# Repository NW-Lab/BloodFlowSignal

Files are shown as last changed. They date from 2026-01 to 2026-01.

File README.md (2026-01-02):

# BloodFlowSignal

複数の非侵襲的センサーを用いて、体のあちこちの心拍と血流動態を測定し、血管の状態を評価するプロジェクトです。

## プロジェクト概要

このプロジェクトは、光電式PPD（Photoplethysmography）の課題を克服し、より詳細な血管情報を取得することを目的としています。複数の異なるセンサー技術を同時に検証し、各手法の利点と欠点を比較することで、最適な血流測定システムの構築を目指します。

### 主な目標

1. **複数部位での心拍測定**: 体のあちこち（胸部、腹部、頸部、腕、脚など）で同時に心拍を測定
2. **血管硬化度の評価**: 脈波伝播速度（PWV）から血管の弾性を定量化
3. **血流動態の推定**: 複数の測定手法から血流速度と血流分布を推定
4. **光電式PPDの代替・比較**: 測定部位の制限やノイズの問題を解決

## センサー構成

本プロジェクトでは、3種類の異なるセンサー技術を実装・比較します。

### 1. マイク方式（MEMS マイクモジュール）

**製品**: [高感度ＭＥＭＳマイクモジュール SPM0404HE5H-T](https://akizukidenshi.com/catalog/g/g103200/)

**特性**:
- 周波数帯域: 100 Hz ～ 10 kHz
- 感度: -42 dBV/Pa
- 小型モジュール設計

**測定対象**:
- 心音（心臓の音）
- 呼吸音
- 体内音による圧力変化

**利点**:
- 聴診器の原理に最も近い
- 心音の周波数特性を詳細に取得可能
- 比較的安価

**欠点**:
- 周囲のノイズに敏感
- ハウジング設計（遮音性）が重要
- 増幅回路が必須

### 2. 圧力センサー方式（ピエゾ抵抗式力センサー）

**製品**: [ピエゾ抵抗式力センサー FSR402](https://akizukidenshi.com/catalog/g/g106078/)

**特性**:
- 測定範囲: 0～10 N
- 応答速度: 高速（音響測定に対応）
- 感圧抵抗型

**測定対象**:
- 体表面の脈動（機械的振動）
- 脈波伝播速度（PWV）
- 脈波形状

**利点**:
- 複数部位の同期測定が容易
- 脈波伝播速度の直接測定が可能
- 環境光の影響を受けない
- 低消費電力

**欠点**:
- ポイント測定のため複数センサーが必要
- 信号処理が必要

### 3. 光学式センサー方式（光電式PPG）

**製品**: [光学式脈波センサーモジュール](https://akizukidenshi.com/catalog/g/g116107/)

**特性**:
- 赤外線LED と フォトダイオード
- 非侵襲的な血流測定
- 従来の光電式PPD

**測定対象**:
- 血液容積の変化
- 脈拍数
- 血流の相対的な変化

**利点**:
- 従来の標準的な方法
- 実装が比較的簡単
- 脈拍数の直接測定

**欠点**:
- 測定部位が限定（指先、手首など）
- 皮膚色や厚さの影響を受けやすい
- ノイズが大きい

## システムアーキテクチャ

```
┌─────────────────────────────────────────────────────┐
│           複数部位センサー配置                        │
├─────────────────────────────────────────────────────┤
│ 胸部     │ 腹部     │ 頸部     │ 腕部     │ 脚部     │
│ (心臓)   │ (大動脈) │ (頸動脈) │ (上腕)   │ (大腿)   │
├─────────────────────────────────────────────────────┤
│ マイク   │ 圧力     │ 光学式   │ 圧力     │ 圧力     │
│ 圧力     │ センサー │ センサー │ センサー │ センサー │
│ 光学式   │          │          │          │          │
└─────────────────────────────────────────────────────┘
         ↓
┌─────────────────────────────────────────────────────┐
│         マイコン（Arduino / ESP32）                  │
│  ├─ アナログ入力処理                                │
│  ├─ デジタル入力処理（SPI）                         │
│  ├─ 信号フィルタリング                              │
│  ├─ ピーク検出                                      │
│  ├─ PWV計算                                        │
│  └─ データ出力                                      │
└─────────────────────────────────────────────────────┘
         ↓
┌─────────────────────────────────────────────────────┐
│         データ処理・可視化                            │
│  ├─ リアルタイムグラフ表示                          │
│  ├─ PWV分析                                        │
│  ├─ 血管硬化度評価                                  │
│  └─ ログ記録                                        │
└─────────────────────────────────────────────────────┘
```

## 主な測定指標

### 1. 脈波伝播速度（PWV: Pulse Wave Velocity）

複数部位での脈波到達時間差から計算：

```
PWV = 距離（m） / 時間差（s）
```

**評価基準**:
- 若い血管: PWV ≈ 15 m/s
- 硬化血管: PWV > 25 m/s

### 2. 血管コンプライアンス（DC: Distensibility Coefficient）

Bramwell-Hill方程式から計算：

```
cPWV = 1/√(ρ × DC)
```

血管の弾性を定量化。

### 3. 脈波形状解析

- 脈波の立ち上がり時間
- ピーク位置
- 脈波の幅
- 反射波の検出

### 4. 血流速度推定

複数センサーからの信号を統合して、血流速度を間接的に推定。

## ディレクトリ構成

```
BloodFlowSignal/
├── README.md                          # このファイル
├── docs/                              # ドキュメント
│   ├── sensor_specifications.md       # センサー仕様書
│   ├── measurement_protocol.md        # 測定プロトコル
│   ├── data_analysis.md               # データ分析方法
│   └── theory.md                      # 理論的背景
├── hardware/                          # ハードウェア設計
│   ├── schematics/                    # 回路図
│   ├── 3d_models/                     # 3Dプリンタ用モデル
│   └── bom.md                         # 部品表
├── firmware/                          # マイコンファームウェア
│   ├── arduino/                       # Arduino用コード
│   ├── esp32/                         # ESP32用コード
│   └── libraries/                     # 必要なライブラリ
├── software/                          # データ処理・可視化ソフト
│   ├── python/                        # Python処理スクリプト
│   ├── visualization/                 # グラフ表示
│   └── analysis/                      # 分析ツール
├── data/                              # 測定データ
│   ├── raw/                           # 生データ
│   ├── processed/                     # 処理済みデータ
│   └── results/                       # 分析結果
└── tests/                             # テストコード
    ├── unit_tests/
    ├── integration_tests/
    └── validation/
```

## クイックスタート

### 必要な部品

**センサー**:
- MEMS マイクモジュール（SPM0404HE5H-T）
- ピエゾ抵抗式力センサー（FSR402） × 5～10個
- 光学式脈波センサーモジュール

**マイコン**:
- Arduino Uno / Nano / Mega
- または ESP32

**その他**:
- ブレッドボード
- ジャンパーワイヤ
- 抵抗・コンデンサ
- 3Dプリンタ用樹脂（外装製作用）

### セットアップ手順

1. **ハードウェアの組立**
   - センサーをマイコンに接続
   - 外装（3Dプリンタ製）に組み込む

2. **ファームウェアの書き込み**
   ```bash
   cd firmware/arduino
   # Arduino IDEで対応するスケッチを開いて書き込み
   ```

3. **ソフトウェアのセットアップ**
   ```bash
   cd software/python
   pip install -r requirements.txt
   ```

4. **初期測定**
   ```bash
   python main.py
   ```

## 測定方法

### 基本的な測定プロトコル

1. **準備**
   - センサーを各部位に装着
   - 安定した姿勢で5分間休息

2. **測定**
   - 各部位で同時に脈波を記録（最低1分間）
   - 複数回測定（3～5回）

3. **分析**
   - 脈波のピーク検出
   - 部位間の時間差計算
   - PWV計算

4. **評価**
   - 血管硬化度の判定
   - 異常値の検出

## 期待される成果

### 短期的（1～3ヶ月）

- 各センサーの基本動作確認
- 信号処理アルゴリズムの開発
- 複数部位測定の実装

### 中期的（3～6ヶ月）

- PWV測定の精度検証
- 血管評価アルゴリズムの構築
- 複数センサーの統合分析

### 長期的（6～12ヶ月）

- 臨床データとの比較検証
- 機械学習による高度な分析
- 製品化への検討

## 技術的な課題と対応

### 1. ノイズ対策

**マイク方式**:
- ハウジング設計による遮音
- デジタルフィルタリング

**圧力センサー方式**:
- 低域フィルタ
- 移動平均フィルタ

**光学式方式**:
- 環境光補正
- 適応フィルタ

### 2. センサー同期

- タイムスタンプの正確な記録
- クロック同期メカニズム

### 3. 温度補正

- 各センサーの温度特性を測定
- 温度補正アルゴリズムの実装

### 4. 個人差への対応

- 体格に応じた距離補正
- 個人別のキャリブレーション

## 参考文献

- Pulse Wave Velocity: Methodology, Clinical Applications, and Interplay with Heart Rate Variability (PMC11317333)
- Transmissive-detected laser speckle contrast imaging for blood flow monitoring (Nature Light: Science & Applications)
- Pulse transit time estimation of aortic pulse wave velocity (PLoS Computational Biology)

## ライセンス

MIT License

## 貢献

このプロジェクトへの貢献を歓迎します。以下の方法で参加できます。

1. フォークしてブランチを作成
2. 変更をコミット
3. プルリクエストを送信

## 連絡先

プロジェクトに関する質問や提案は、GitHubのIssuesで報告してください。

## 更新履歴

- 2026-01-02: プロジェクト初期化、README作成

---

**注意**: このプロジェクトは研究・開発目的です。医療診断目的での使用は、適切な検証と認可を得た後に行ってください。

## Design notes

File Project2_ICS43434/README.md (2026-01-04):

# Project2: M5AtomS3とICS-43434マイクによる血流計測

## 1. はじめに

本プロジェクトは、M5Stack社のM5AtomS3とTDK InvenSense社のICS-43434 MEMSマイクを使用して、血流音を非侵襲的に計測するシステムの構築を目的とします。取得したデータはPC上のシリアルプロッターでリアルタイムに可視化し、心拍などの生体情報の簡易的なモニタリングを目指します。

## 2. 使用機材

本プロジェクトで使用する主要なハードウェアは以下の通りです。

| 機材名 | メーカー | モデル | 概要 |
| :--- | :--- | :--- | :--- |
| マイコン | M5Stack | M5AtomS3 | ESP32-S3を搭載した小型マイコンモジュール [1] |
| マイク | TDK InvenSense | ICS-43434 | I2Sデジタル出力対応のMEMSマイク [2] |

### M5AtomS3

M5AtomS3は、Wi-Fi機能を内蔵した強力なESP32-S3プロセッサ、8MBのフラッシュメモリ、0.85インチのIPSスクリーンを搭載した、非常にコンパクトで多機能な開発モジュールです。USB-Cポート経由での給電とプログラム書き込みが可能で、プロトタイピングに最適です。

### ICS-43434 MEMSマイク

ICS-43434は、高感度かつ低ノイズなデジタルMEMSマイクです。I2Sインターフェースを通じて24ビットのデジタルオーディオデータを出力するため、アナログ回路の設計が不要で、ノイズの影響を受けにくいクリーンな音声信号を取得できます。本プロジェクトでは、このマイクを用いて皮膚表面の微弱な血流音を捉えます。

## 3. ハードウェア接続

M5AtomS3とICS-43434マイクは、以下の表と配線図に従ってI2Sインターフェースで接続します。

| M5AtomS3 Pin | ICS-43434 Pin | 信号名 | 役割 |
| :--- | :--- | :--- | :--- |
| G5 | SCK | I2S Serial Clock | I2Sのビットクロック |
| G6 | WS | I2S Word Select | 左右チャンネルの選択クロック |
| G7 | SD | I2S Serial Data | マイクからのデジタル音声データ |
| 3V3 | VIN | Power | マイクへの電源供給 (3.3V) |
| GND | GND | Ground | グランド接続 |
| GND | SEL | Channel Select | チャンネル選択（GNDに接続してLeftチャンネルに設定） |

## 4. ソフトウェア

開発環境としてArduino IDEを使用し、M5AtomS3にプログラムを書き込みます。取得したデータは、USBシリアル通信を介してPCに送信され、Arduino IDEに標準で搭載されている「シリアルプロッター」機能を用いてリアルタイムで波形を可視化します。

## 5. 測定原理

手首や首などの皮膚表面に近い動脈の拍動は、微弱な音（血流音）を発生させます。ICS-43434マイクは、この音を捉えるのに十分な感度と周波数特性（50Hz〜15kHz）を持っています。取得した音声データから、心拍に同期した周期的な信号を検出することで、心拍数を推定することが可能になります。

## 6. 今後の展望

本プロジェクトで構築したシステムを基盤として、将来的には以下の様な機能拡張が考えられます。

*   **FFT（高速フーリエ変換）による周波数解析**: 血流音の周波数成分を分析し、より詳細な生体情報を抽出します。
*   **心拍数（BPM）の自動計算**: 検出した波形からピークを検出し、リアルタイムで心拍数を計算・表示します。
*   **データの保存と分析**: 計測データをファイルに保存し、長期的な健康状態のモニタリングや、機械学習を用いた異常検知などに応用します。

## 7. 参考文献

[1] M5Stack. (n.d.). *AtomS3*. M5Stack Documentation. Retrieved from https://docs.m5stack.com/en/core/AtomS3
[2] Adafruit Industries. (n.d.). *Adafruit I2S MEMS Microphone Breakout - ICS-43434*. Retrieved from https://www.adafruit.com/product/6049

## 8. 3Dプリント用ケース

血流計測の精度を向上させるため、ICS-43434マイクを皮膚に直接当てるための専用ケースを設計しました。

### ケースの特徴

*   **直接接触型**: マイクの音孔が皮膚に直接当たる構造で、振動を効率的に伝達
*   **遮音設計**: 周囲の環境音を遮断し、血流音のみを捉える
*   **持ちやすい形状**: 円筒形の持ち手で安定した測定が可能
*   **調整可能な設計**: STEP形式ファイルでFusion 360による編集が可能

### CADファイル

`CAD/`ディレクトリに以下のファイルが含まれています：

*   `microphone_case.stl` - 3Dプリント用（ケース本体）
*   `microphone_case.step` - Fusion 360編集用（ケース本体）
*   `microphone_lid.stl` - 3Dプリント用（マイク固定蓋）
*   `microphone_lid.step` - Fusion 360編集用（マイク固定蓋）

詳細な使用方法と設計仕様については、[CAD/README.md](CAD/README.md)を参照してください。

### 3Dプリント推奨設定

*   材質: PLA または ABS
*   積層ピッチ: 0.2mm
*   インフィル: 20-30%
*   プリント方向: 底面を下にして配置

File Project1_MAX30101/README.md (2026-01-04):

# Project1_MAX30101: M5AtomS3による血流計測（緑LED版）

## 概要

このプロジェクトでは、M5AtomS3マイクロコントローラーとSparkFun社のSEN-16474（MAX30101搭載）光検出器ブレークアウトボードを使用して、血流の変動を計測します。センサーから取得した**緑色光**の反射データをシリアル通信経由でPCに出力し、グラフ化することを目的とします。

緑色LEDは皮膚表面の血流変化を検出するのに最も感度が高く、心拍数測定において高いSN比（信号対雑音比）が期待できます。

## 使用機材

| 役割 | 型番 | メーカー |
|---|---|---|
| マイクロコントローラー | M5AtomS3 | M5Stack |
| センサー | SEN-16474 (MAX30101) | SparkFun |

## 接続

M5AtomS3とMAX30101センサーはI2Cインターフェースで接続します。M5AtomS3のGroveポート（HY2.0-4P）はI2C通信に対応していないため、背面のピンヘッダを使用します。

| M5AtomS3 (背面ピン) | MAX30101 (ブレークアウト) |
|---|---|
| 3.3V | 3.3V |
| GND | GND |
| G39 (SCL) | SCL |
| G38 (SDA) | SDA |

**注意:** SparkFunのブレークアウトボードはQwiicコネクタを搭載していますが、M5AtomS3のGroveポートとは互換性がありません。接続には注意してください。また、緑LEDの性能を最大限に引き出すには、センサーのVLEDピンに5Vを供給することが推奨されていますが、3.3Vでも動作します。

## セットアップ

### 1. Arduino IDEの環境設定

Arduino IDEにESP32ボードマネージャをインストールし、M5Stackのボード定義を追加する必要があります。詳細はM5Stackの公式ドキュメントを参照してください。

- [M5Stack Arduino Quick Start][1]

### 2. 必要なライブラリのインストール

Arduino IDEのライブラリマネージャから、以下の2つのライブラリをインストールしてください。

- **SparkFun MAX3010x Pulse and Proximity Sensor Library**: MAX30101センサーを制御するためのライブラリです。
- **M5Unified**: M5Stack製品群を統一的に扱うためのライブラリです。

## 使用方法

1.  このディレクトリにある`Project1_MAX30101.ino`をArduino IDEで開きます。
2.  M5AtomS3をPCに接続し、ボードとシリアルポートを正しく設定します。
3.  コードをM5AtomS3に書き込みます。
4.  Arduino IDEのシリアルプロッタ（`ツール` > `シリアルプロッタ`）を開き、ボーレートを`115200`に設定します。
5.  センサーに指を置くと、緑色光のデータがグラフとして表示されます。

## 外光ノイズ対策

MAX30101は、**Ambient Light Cancellation (ALC)** という強力な外光ノイズ除去機能を内蔵しています。この機能は、センサー内部のTrack/Hold回路によって外光の影響を自動的に測定値から差し引くことで、ダイナミックレンジを向上させます。

Arduinoコードでは、`particleSensor.setup()`関数を呼び出すことでALC機能が**自動的に有効化**されます。特別な設定は不要です。

## 注意事項

- このプロジェクトで得られるデータは、医療目的の診断や生命維持のためには使用できません。あくまで教育およびデモンストレーション目的のものです。

## 参考資料

1.  [M5Stack Docs - AtomS3][2]
2.  [SparkFun Photodetector (MAX30101) Hookup Guide][3]
3.  [MAX30101 Datasheet][4]
4.  [How to select the green LED only on the MAX30101][5]

[1]: https://docs.m5stack.com/en/arduino/atomS3
[2]: https://docs.m5stack.com/en/core/AtomS3
[3]: https://learn.sparkfun.com/tutorials/sparkfun-photodetector-max30101-hookup-guide/all
[4]: https://www.analog.com/media/en/technical-documentation/data-sheets/max30101.pdf
[5]: https://ez.analog.com/optical_sensing/w/documents/20560/how-to-select-the-green-led-only-on-the-max30101

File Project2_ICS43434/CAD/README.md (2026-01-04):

# ICS-43434マイク用血流計測ケース - 3D CADファイル

## 概要

このディレクトリには、ICS-43434 MEMSマイクを使用した血流計測用ケースの3D CADファイルが含まれています。ケースは皮膚に直接当てて使用する設計で、環境音を遮断しながら血流音を効率的に捉えることができます。

## ファイル一覧

### ケース本体

| ファイル名 | 形式 | 用途 |
| :--- | :--- | :--- |
| `microphone_case.stl` | STL | 3Dプリント用（ケース本体） |
| `microphone_case.step` | STEP | Fusion 360で編集可能（ケース本体） |

### 蓋（オプション）

| ファイル名 | 形式 | 用途 |
| :--- | :--- | :--- |
| `microphone_lid.stl` | STL | 3Dプリント用（マイク固定蓋） |
| `microphone_lid.step` | STEP | Fusion 360で編集可能（マイク固定蓋） |

## 設計仕様

### ケース本体の寸法

*   **ベース部直径**: 30mm（皮膚接触面）
*   **ベース部高さ**: 10mm
*   **持ち手部直径**: 20mm
*   **持ち手部高さ**: 40mm
*   **全体高さ**: 50mm
*   **壁厚**: 2mm

### マイク収納部

*   **基板収納スペース**: 17mm × 13.5mm × 2.5mm
*   **音孔開口部**: 直径6mm（底面中央）
*   **ケーブル切り欠き**: 幅6mm × 高さ4mm

## 使用方法

### 1. 3Dプリント

**推奨設定:**
*   材質: PLA または ABS
*   積層ピッチ: 0.2mm
*   インフィル: 20-30%
*   サポート材: 必要に応じて使用
*   プリント方向: 底面を下にして配置

**注意事項:**
*   音孔部分は貫通している必要があるため、プリント後に確認してください
*   接触面（底面）は平滑に仕上げることで、皮膚への密着性が向上します

### 2. マイクの取り付け

1. ICS-43434ブレイクアウトボードをケース上部の収納スペースに配置
2. マイクの音孔（底面ポート）がケース底面の開口部に向くように配置
3. 蓋を使用してマイクを固定（または接着剤で固定）
4. ケーブルを側面の切り欠きから引き出す

### 3. 使用時の注意

*   マイクの音孔が皮膚に直接当たるように配置してください
*   適度な圧力で皮膚に押し当てます（強く押しすぎないこと）
*   測定中はケースを動かさないように保持してください

## Fusion 360での編集

STEP形式のファイル（`microphone_case.step`）をAutodesk Fusion 360で開くことで、寸法や形状を自由に編集できます。

### 編集可能なパラメータ

*   ベース部・持ち手部の直径と高さ
*   マイク収納部のサイズ
*   音孔の直径
*   ケーブル切り欠きの位置とサイズ
*   壁厚

### 編集後の再生成

Pythonスクリプト（`generate_microphone_case.py`）を使用すれば、パラメータを変更して新しいモデルを生成できます。スクリプト内の定数を編集してから実行してください。

```bash
# 仮想環境をアクティベート
source venv/bin/activate

# スクリプトを実行
python generate_microphone_case.py
```

## 設計の背景

### 直接接触型を採用した理由

血流音は皮膚表面の微細な振動として現れます。この振動を効率的に捉えるため、マイクを皮膚に直接密着させる設計を採用しました。空気層を介さないことで、以下のメリットがあります：

*   **振動の直接伝達**: 機械的振動を効率的にマイクに伝える
*   **ノイズの低減**: 周囲の環境音（話し声、風、機械音など）の混入を防ぐ
*   **測定の安定性**: 空気層による音響特性の変動を排除

### 形状の工夫

*   **円筒形のベース**: 皮膚への均等な接触を実現
*   **持ち手部**: 安定した保持と適度な圧力の調整が可能
*   **遮音構造**: 側面からの環境音の侵入を最小限に抑制

## ライセンス

このCADファイルはオープンソースとして公開されています。自由に改変・再配布が可能です。

## 参考資料

*   [ICS-43434 データシート](https://invensense.tdk.com/wp-content/uploads/2016/02/DS-000069-ICS-43434-v1.2.pdf)
*   [Adafruit ICS-43434 製品ページ](https://www.adafruit.com/product/6049)
*   [CadQuery ドキュメント](https://cadquery.readthedocs.io/)

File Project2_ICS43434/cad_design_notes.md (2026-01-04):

# ICS-43434マイク用ケース設計メモ

## ブレイクアウトボードの寸法

Adafruit ICS-43434 ブレイクアウトボード（製品番号: 6049）の寸法：
- 基板サイズ: 約16.5mm × 12.7mm
- 厚さ: 約1.8mm
- 取り付け穴: 直径約2.5mm（4隅）
- マイク位置: 基板中央付近
- 音孔（ポート）: 基板底面（ボトムポート）

参考: https://learn.adafruit.com/adafruit-i2s-mems-microphone-breakout/downloads

## 設計コンセプト

### 目的
血流音を計測するため、マイクを皮膚に直接当てて使用するケース

### 設計方針
1. **直接接触型**: マイクの音孔が皮膚に直接当たる構造
2. **遮音性**: 周囲の環境音を遮断
3. **安定保持**: 手で持ちやすく、測定中に動かない
4. **適度な圧力**: 皮膚に軽く押し当てられる

## ケース設計仕様

### 全体構造
- 形状: 円筒形ベース + 持ち手
- 材質想定: PLA/ABS（3Dプリント）

### 寸法
- ベース部直径: 30mm（皮膚接触面）
- ベース部高さ: 10mm
- 持ち手部直径: 20mm
- 持ち手部高さ: 40mm
- 全体高さ: 約50mm

### マイク固定部
- 基板収納スペース: 17mm × 13.5mm × 2mm（余裕を持たせる）
- 音孔開口部: 直径5mm（マイク位置に合わせる）
- 固定方法: スナップフィット or ネジ固定

### 接触面
- 平面形状（皮膚に均等に当たる）
- 音孔開口部のみ貫通
- エッジは面取り（皮膚への刺激を軽減）

### ケーブル引き出し
- 側面に切り欠き（ケーブル用）
- 幅: 5mm

## 設計パラメータ（調整可能）

```python
# 基本寸法
base_diameter = 30.0  # ベース部直径 (mm)
base_height = 10.0    # ベース部高さ (mm)
handle_diameter = 20.0  # 持ち手直径 (mm)
handle_height = 40.0   # 持ち手高さ (mm)

# マイク基板
pcb_width = 17.0      # 基板幅 (mm)
pcb_length = 13.5     # 基板長さ (mm)
pcb_thickness = 2.0   # 基板厚さ (mm)

# 音孔
port_diameter = 5.0   # 音孔直径 (mm)

# 壁厚
wall_thickness = 2.0  # 壁の厚さ (mm)
```

## 製造方法
- 3Dプリント（FDM方式）
- 推奨積層ピッチ: 0.2mm
- サポート材: 必要に応じて使用

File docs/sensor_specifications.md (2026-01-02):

# センサー仕様書

## 1. MEMS マイクモジュール（SPM0404HE5H-T）

### 基本仕様

| 項目 | 仕様 |
|---|---|
| 製品名 | 高感度ＭＥＭＳマイクモジュール |
| 型番 | SPM0404HE5H-T |
| 周波数帯域 | 100 Hz ～ 10 kHz |
| 感度 | -42 dBV/Pa |
| パッケージ | BGA |
| 供給電圧 | 1.5 V ～ 3.6 V |
| 消費電流 | 約 0.5 mA |

### 特性

- **周波数特性**: 100 Hz から 10 kHz の範囲で良好な感度
- **心音周波数帯域**: 20 Hz ～ 650 Hz をカバー（100 Hz 以上）
- **呼吸音周波数帯域**: 100 Hz ～ 1000 Hz をカバー
- **小型**: 5.0 mm × 3.0 mm × 1.2 mm

### 接続方法

```
VDD -----> 電源（1.5V～3.6V）
GND -----> グラウンド
OUT -----> オーディオ出力（アナログ）
```

### 使用上の注意

1. **ハウジング設計が重要**: 周囲のノイズを遮断するため、マイクを密閉容器に収める
2. **増幅回路が必須**: マイクからの出力は非常に微弱なため、オペアンプで増幅が必要
3. **ノイズフィルタリング**: デジタルフィルタリングで環境ノイズを除去

### 測定対象

- 心音（心臓の音）
- 呼吸音
- 体内音による圧力変化

---

## 2. ピエゾ抵抗式力センサー（FSR402）

### 基本仕様

| 項目 | 仕様 |
|---|---|
| 製品名 | ピエゾ抵抗式力センサー |
| 型番 | FSR402 |
| 測定範囲 | 0～10 N |
| 感度 | 圧力依存（非線形） |
| 応答時間 | < 1 ms |
| パッケージ | 円形（直径 12.7 mm） |
| 供給電圧 | 5 V |

### 特性

- **応答速度**: 0.8 ms（脈波測定に十分）
- **周波数帯域**: 約 1.25 kHz（心音・呼吸音をカバー）
- **非線形特性**: 圧力が増加するほど抵抗値が低下
- **温度特性**: 温度による変化あり（補正が必要）

### 接続方法

```
FSR402を分圧回路で使用：

        5V
        |
        R（10kΩ）
        |
    +---+----> ADC入力
    |
   FSR402
    |
   GND
```

### 使用上の注意

1. **分圧回路が必須**: FSR402は可変抵抗のため、分圧回路で電圧に変換
2. **温度補正**: 温度による特性変化を補正
3. **キャリブレーション**: 個別のキャリブレーションが必要
4. **複数個使用**: 複数部位測定には複数個のセンサーが必要

### 測定対象

- 体表面の脈動（機械的振動）
- 脈波伝播速度（PWV）
- 脈波形状

---

## 3. 光学式脈波センサーモジュール

### 基本仕様

| 項目 | 仕様 |
|---|---|
| 製品名 | 光学式脈波センサーモジュール |
| 型番 | （確認中） |
| 光源 | 赤外線LED（660 nm または 940 nm） |
| 検出器 | フォトダイオード |
| 周波数帯域 | DC ～ 数 kHz |
| 供給電圧 | 3.3 V ～ 5 V |
| 消費電流 | 約 10～20 mA |

### 特性

- **非侵襲的**: 皮膚表面の血流を光学的に測定
- **脈拍検出**: 血液容積の変化から脈拍を検出
- **相対測定**: 絶対的な血流量ではなく、相対的な変化を測定

### 接続方法

```
LED+ -----> 電源（制限抵抗経由）
LED- -----> GND
PD+ -----> アナログ入力（増幅回路経由）
PD- -----> GND
```

### 使用上の注意

1. **測定部位の限定**: 指先、手首など、光が透過する部位のみ
2. **皮膚色の影響**: メラニン色素が多い場合、信号が弱くなる
3. **環境光の影響**: 外部光源の変動が測定値に影響
4. **密着性が重要**: センサーと皮膚の密着度が測定精度に影響

### 測定対象

- 血液容積の変化
- 脈拍数
- 血流の相対的な変化

---

## センサー比較表

| 特性 | マイク | 圧力センサー | 光学式 |
|---|---|---|---|
| **周波数帯域** | 100 Hz ～ 10 kHz | DC ～ 1.25 kHz | DC ～ 数 kHz |
| **応答速度** | 高速 | 高速（< 1 ms） | 中速 |
| **測定部位** | 任意 | 任意 | 限定（指先など） |
| **ノイズ耐性** | 低 | 高 | 中 |
| **環境光影響** | なし | なし | あり |
| **複数部位対応** | 容易 | 容易 | 困難 |
| **コスト** | 低 | 低 | 低 |
| **実装難易度** | 中 | 低 | 低 |

---

## 信号処理フロー

### マイク方式

```
マイク出力
  ↓
増幅回路
  ↓
ADC変換
  ↓
デジタルフィルタリング（ハイパスフィルタ）
  ↓
周波数解析（FFT）
  ↓
心音検出・分析
```

### 圧力センサー方式

```
FSR402出力
  ↓
分圧回路
  ↓
ADC変換
  ↓
デジタルフィルタリング（ローパス＋ハイパス）
  ↓
ピーク検出
  ↓
時間差計算
  ↓
PWV計算
```

### 光学式方式

```
フォトダイオード出力
  ↓
増幅回路
  ↓
ADC変換
  ↓
デジタルフィルタリング
  ↓
ピーク検出
  ↓
脈拍数計算
```

---

## キャリブレーション方法

### マイク方式

1. 既知の周波数信号を入力
2. 出力の周波数特性を測定
3. 補正係数を計算

### 圧力センサー方式

1. 既知の圧力を加える
2. 出力電圧を測定
3. 圧力-電圧特性曲線を作成
4. 非線形補正を実装

### 光学式方式

1. 既知の脈拍数で測定
2. 検出された脈拍数と比較
3. 補正係数を計算

---

## トラブルシューティング

### マイク方式

| 問題 | 原因 | 対策 |
|---|---|---|
| 出力が小さい | 増幅不足 | 増幅回路のゲインを上げる |
| ノイズが多い | 外部ノイズ | ハウジング改善、フィルタ強化 |
| 周波数特性が悪い | フィルタ設定 | フィルタ係数を調整 |

### 圧力センサー方式

| 問題 | 原因 | 対策 |
|---|---|---|
| 出力が不安定 | 接触不良 | センサー接触面を確認 |
| 温度ドリフト | 温度変化 | 温度補正を実装 |
| 非線形性 | センサー特性 | 非線形補正を実装 |

### 光学式方式

| 問題 | 原因 | 対策 |
|---|---|---|
| 信号が弱い | 皮膚色 | LED電流を増加 |
| ノイズが多い | 環境光 | 環境光補正を実装 |
| 脈拍検出失敗 | 密着不良 | センサー装着を改善 |

---

## 参考資料

- SPM0404HE5H-T データシート
- FSR402 データシート
- 光学式脈波センサー仕様書

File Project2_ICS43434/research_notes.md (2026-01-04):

# ICS-43434マイクとM5AtomS3の調査結果

## ICS-43434 MEMS マイクロフォン仕様

### 基本情報
- 製品: Adafruit I2S MEMS Microphone Breakout - ICS-43434
- 製品URL: https://www.adafruit.com/product/6049
- チップ: TDK ICS43434
- インターフェース: I2S (デジタル出力)

### 技術仕様
- 感度: −26 dB FS ±1dB
- SNR (High Performance Mode): 65 dBA
- SNR (Low Power Mode): 64 dBA
- 消費電流 (High Performance Mode): 490 µA
- 消費電流 (Low Power Mode): 230 µA
- Acoustic Overload Point (AOP): 120 dB SPL
- サンプルレート (High Performance Mode): 23 ~ 51.6 kHz
- サンプルレート (Low Power Mode): 6.25 ~ 18.75 kHz
- 周波数範囲: 50Hz - 15KHz (一般的なオーディオ記録に適している)
- ローパスフィルター: 24KHz以上をカット
- データ出力: 24ビット

### ピン配置
- Clock (SCK/BCK): I2Sクロック信号
- Data (SD): I2Sデータ出力
- Word Select (WS/LRCLK): 左右チャンネル選択
- Select (SEL): チャンネル選択 (GND=Left, VDD=Right)
- VIN: 電源入力 (1.6V - 3.6V)
- GND: グランド

### 重要な特徴
- モノラルマイク（ステレオには2個必要）
- ボトムポート（底面に音孔）
- 5Vロジックには非対応（3.3V専用）
- ESP32、RP2040、SAMD21/51などのI2S対応マイコンに最適

## M5AtomS3 仕様

### 基本情報
- 製品URL: https://docs.m5stack.com/en/core/AtomS3
- SoC: ESP32-S3FN8
- Flash: 8MB
- サイズ: 24.0 x 24.0 x 12.9mm

### 電源仕様
- 入力電源: 5V (USB Type-C)
- 出力電圧: 3.3V
- DC-DC: SY8089

### 利用可能なGPIOピン
- G5, G6, G7, G8, G38, G39 (底面に配置)

### I2C使用状況
- MPU6886 (IMU): I2C Address 0x68
  - SDA: GPIO38
  - SCL: GPIO39

### 内蔵ペリフェラル
- 0.85インチ LCD (SPI接続)
  - MOSI: G21
  - SCK: G17
  - CS: G15
  - RS: G33
  - RST: G34
  - LCD_BL: G16

### HY2.0-4Pポート
- GND: Black
- 5V: Red
- G2: Yellow
- G1: White

### I2S接続の推奨ピン
ESP32-S3はI2S0とI2S1の2つのI2Sペリフェラルを持つ。
利用可能なGPIOピン（G5, G6, G7, G8）をI2S接続に使用可能。

推奨配線:
- I2S SCK (Clock): GPIO5
- I2S WS (Word Select): GPIO6
- I2S SD (Data): GPIO7
- SEL: GND (Left channel) または 3.3V (Right channel)
- VIN: 3.3V
- GND: GND

## 血流計測への応用

### 測定原理
マイクロフォンを使用して血流音（血管の拍動音）を検出する。
- 皮膚表面に近い血管（手首、首など）の拍動音を検出
- 低周波成分（1-10Hz程度）に心拍情報が含まれる
- ICS-43434の周波数範囲は50Hz-15KHzなので、低周波の心拍音検出に適している

### データ処理
1. I2Sインターフェースで24ビットデジタルデータを取得
2. サンプリングレート: 16kHz または 44.1kHz
3. データをシリアル経由でPCに送信
4. Arduino IDEのシリアルプロッターでリアルタイム表示

## 参考資料
- ICS-43434 Datasheet: https://invensense.tdk.com/wp-content/uploads/2016/02/DS-000069-ICS-43434-v1.2.pdf
- Adafruit製品ガイド: https://learn.adafruit.com/adafruit-i2s-mems-microphone-breakout
- M5AtomS3 Arduino Library: https://github.com/m5stack/M5Unified
- ESP32-S3 I2S Documentation: https://docs.espressif.com/projects/esp-idf/en/stable/esp32s3/api-reference/peripherals/i2s.html

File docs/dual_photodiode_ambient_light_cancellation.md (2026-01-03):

# 2個フォトダイオード方式の外光除去技術

## 概要

光学式PPGセンサーにおいて、受光部（フォトダイオード）が2個ある場合の外光除去技術について解説します。この技術は、**LED ON-OFF方式と同じ基本原理**（時間的な差分を取る）を使用しますが、**アナログ領域で電荷再分配により実現**する点が大きく異なります。

---

## 基本原理: 交互サンプリングと電荷再分配

### 動作の概要

2個フォトダイオード方式（正確には**2個電荷リザーバ方式**）では、以下の3つのフェーズで外光除去を行います。

1. **Phase 1**: LED ON時に信号をサンプリングし、電荷リザーバCrに保存
2. **Phase 2**: LED OFF時に信号をサンプリングし、電荷リザーバCaに保存
3. **Phase 3**: 2つの電荷リザーバを**逆極性で接続**し、電荷再分配により差分を取る

この方式により、外光成分が物理的に打ち消され、純粋なPPG信号のみが抽出されます。

---

## 詳細な動作原理

### Phase 1: LED ON時のサンプリング

**スイッチ状態**:
- Switch S1: 接続
- Switch S2, S3: 切断

**測定内容**: LED光（PPG信号）+ 外光

**保存先**: 電荷リザーバ Cr

**保存される電荷**:
```
Qr = Cr × V_ph1
```

ここで、`V_ph1 = V_LED + V_AL`
- `V_LED`: LED光による信号（PPG信号）
- `V_AL`: 外光による信号（ノイズ）

### Phase 2: LED OFF時のサンプリング

**スイッチ状態**:
- Switch S1: 切断
- Switch S2: 接続
- Switch S3: 切断

**測定内容**: 外光のみ

**保存先**: 電荷リザーバ Ca

**保存される電荷**:
```
Qa = Ca × V_ph2
```

ここで、`V_ph2 = V_AL`（LED OFFのため、外光のみ）

### Phase 3: 電荷再分配

**スイッチ状態**:
- Switch S1, S2: 切断
- Switch S3: 接続

**動作**: CrとCaを**逆極性で接続**

**極性制御**:
- `Polarity = High`: Crのプラスノードを Caのマイナスノードに接続
- `Polarity = Low`: Crのプラスノードを Caのプラスノードに接続

**出力電圧**（Cr = Caの場合）:
```
V_out = (V_ph1 - V_ph2) / 2
      = (V_LED + V_AL - V_AL) / 2
      = V_LED / 2
```

**結果**: 外光成分（V_AL）が完全に除去され、LED光による信号（PPG信号）のみが残ります。

---

## LED ON-OFF方式との比較

| 項目 | LED ON-OFF方式（デジタル差分） | 2個電荷リザーバ方式（アナログ差分） |
|---|---|---|
| **基本原理** | LED ON時とOFF時の差分を取る | 同じ（時間的な差分） |
| **差分計算の場所** | デジタル演算（マイコン内） | アナログ回路（電荷再分配） |
| **外光除去のタイミング** | ADC変換後、デジタル演算で除去 | ADC変換前、アナログ段階で除去 |
| **消費電力** | 中程度（ADC + デジタル演算） | 低い（アナログ回路のみ） |
| **ダイナミックレンジ** | 外光成分がADCレンジを占有 | 外光除去後にADC変換（有効活用） |
| **精度** | ADC分解能に依存 | 電荷再分配の精度に依存 |
| **回路複雑度** | 低い（シンプル） | 中程度（スイッチ制御が必要） |
| **リアルタイム性** | デジタル演算の遅延あり | 瞬時に完了（遅延ほぼなし） |
| **実装** | マイコン + ADC | 電荷リザーバ + スイッチ + 制御回路 |

---

## 利点と欠点

### 利点

**1. 低消費電力**

アナログ領域で外光除去が完了するため、デジタル演算が不要です。これにより、消費電力を大幅に削減できます。

**実測値**: 26.4 μW（Kim et al., 2015）

**2. 高ダイナミックレンジ**

外光成分を除去してからADC変換するため、ADCのダイナミックレンジをPPG信号に集中できます。これにより、微弱なPPG信号を高精度に測定可能です。

**3. リアルタイム処理**

電荷再分配は瞬時に完了するため、リアルタイムで外光除去が可能です。遅延がほとんどありません。

**4. 高精度**

電荷再分配により、外光成分を物理的に打ち消すため、デジタル演算による丸め誤差がありません。

### 欠点

**1. 回路複雑度の増加**

2つの電荷リザーバ（コンデンサ）とスイッチ制御回路が必要です。タイミング制御が重要になります。

**2. 電荷リザーバのマッチング**

CrとCaのキャパシタンスが正確に一致している必要があります。マッチング誤差があると、外光除去が不完全になります。

**3. スイッチのリーク電流**

スイッチのリーク電流により、保存された電荷が減衰する可能性があります。高品質なスイッチ（低リーク電流 <1 pA）が必要です。

**4. 集積回路（IC）化が必要**

この技術は、通常、専用の集積回路（ASIC）として実装されます。ディスクリート部品での実装は困難です。

---

## 実装上の注意点

### 1. タイミング制御

Phase 1、Phase 2、Phase 3のタイミングを正確に制御する必要があります。

**推奨タイミング**:
- **Phase 1（LED ON）**: 4 ms
- **Phase 2（LED OFF）**: 4 ms
- **Phase 3（電荷再分配）**: 数μs～数十μs

**タイミング図**:
```
LED:     ████████________████████________
         |  ON  |  OFF  |  ON  |  OFF  |
         
Phase:   |  1   |   2   |  1   |   2   |
         
Switch:  S1 ON  S2 ON   S1 ON  S2 ON
         S3 OFF S3 OFF  S3 OFF S3 OFF
         
Charge:  Cr保存 Ca保存  Cr保存 Ca保存
         
Output:         S3 ON          S3 ON
                再分配          再分配
```

### 2. 電荷リザーバのサイズ

電荷リザーバ（Cr, Ca）のキャパシタンスは、以下の要素を考慮して決定します。

**大きいキャパシタンス（例: 10 pF以上）**:
- **利点**: ノイズ耐性が高い、リーク電流の影響が小さい
- **欠点**: チップ面積が大きい、電荷再分配に時間がかかる

**小さいキャパシタンス（例: 1 pF以下）**:
- **利点**: チップ面積が小さい、高速動作
- **欠点**: ノイズ耐性が低い、リーク電流の影響が大きい

**推奨値**: 3～10 pF（ノイズ耐性と速度のバランス）

### 3. スイッチの選択

スイッチには、低リーク電流、低オン抵抗、高速スイッチングが求められます。

**推奨スイッチ**:
- **CMOS伝送ゲート（Transmission Gate）**: NMOSとPMOSを並列接続
- **低リーク電流**: <1 pA
- **低オン抵抗**: <100 Ω
- **スイッチング時間**: <1 μs

### 4. マッチング精度

CrとCaのキャパシタンスは、高精度でマッチングする必要があります。

**推奨マッチング精度**: ±0.1%以内

**実装方法**:
- 同じレイアウト、同じサイズのキャパシタを使用
- 温度変動の影響を最小化するため、温度係数の小さいキャパシタを選択

---

## 本プロジェクトでの適用可能性

### 使用予定の光学式センサー

**製品**: [秋月電子 光学式脈波センサー](https://akizukidenshi.com/catalog/g/g116107/)

このセンサーは、既製品のモジュールであり、内部回路の詳細は不明です。おそらく、以下のいずれかの方式を使用していると推定されます。

1. **LED ON-OFF方式（デジタル差分）**: 最も一般的
2. **2個電荷リザーバ方式（アナログ差分）**: 高性能モジュールの場合

### 実装方法

**ケース1: モジュールがLED ON-OFF方式を使用している場合**

マイコン（Seeeduino XIAO）で以下の処理を実装します。

1. LED ON時にADCサンプリング → `V_on`
2. LED OFF時にADCサンプリング → `V_off`
3. デジタル演算で差分を計算 → `V_ppg = V_on - V_off`

**ケース2: モジュールが2個電荷リザーバ方式を使用している場合**

モジュール内部で外光除去が完了しているため、マイコンでは単純にADCサンプリングするだけで済みます。

**推奨**: まずは、モジュールのデータシートを確認し、内部回路の詳細を把握することが重要です。データシートが入手できない場合は、実験的にLED ON-OFF方式を実装し、外光除去の効果を確認してください。

---

## 参考文献

1. Jongpal Kim, Jihoon Kim, Hyoungho Ko, "Low-Power Photoplethysmogram Acquisition Integrated Circuit with Robust Light Interference Compensation," Sensors, 2015.
   - DOI: 10.3390/s16010046
   - PMCID: PMC4732079

2. 島崎拓則ら, "光電脈波計の原理を利用した適応フィルタによる運動中の心拍数センシング," 生体医工学, 2016.

3. Analog Devices, "ADPD144RI Data Sheet," 2019.

4. Maxim Integrated (Analog Devices), "MAX86177 Data Sheet," 2022.

---

## まとめ

2個フォトダイオード方式（正確には2個電荷リザーバ方式）の外光除去技術は、**LED ON-OFF方式と同じ基本原理**（時間的な差分を取る）を使用しますが、**アナログ領域で電荷再分配により実現**する点が大きく異なります。

この方式は、**低消費電力**、**高ダイナミックレンジ**、**リアルタイム処理**という利点があり、ウェアラブルデバイスに最適です。ただし、回路複雑度が増加し、電荷リザーバのマッチングとスイッチのリーク電流に注意が必要です。

本プロジェクトでは、使用予定の光学式センサーモジュールの内部回路を確認し、適切な実装方法を選択することが重要です。

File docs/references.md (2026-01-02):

# 参考文献・技術資料

本プロジェクトで参考にした論文、技術資料、データシートをまとめています。

---

## 目次

1. [脈波伝播速度（PWV）と血管評価](#脈波伝播速度pwvと血管評価)
2. [脈波到達時間（PAT）と血圧推定](#脈波到達時間patと血圧推定)
3. [光学式血流測定](#光学式血流測定)
4. [センサー技術](#センサー技術)
5. [データシート](#データシート)
6. [その他の技術資料](#その他の技術資料)

---

## 脈波伝播速度（PWV）と血管評価

### 主要論文

#### 1. Pulse transit time estimation of aortic pulse wave velocity and blood pressure using machine learning and simulated training data

**著者**: Janne M J Huttunen, Leo Kärkkäinen, Harri Lindholm  
**掲載誌**: PLoS Computational Biology, 2019  
**URL**: https://pmc.ncbi.nlm.nih.gov/articles/PMC6711549/  
**DOI**: 10.1371/journal.pcbi.1007259

**概要**:
- 心血管モデリングを用いた仮想被験者データベースの生成
- 機械学習（ガウス過程回帰）による大動脈PWV、血圧、一回拍出量の推定
- 光電式PPG信号から導出された脈波通過時間を使用
- 大動脈PWVの推定精度: r > 0.9（左頸動脈測定時）

**本プロジェクトへの示唆**:
- 複数部位での脈波測定から機械学習でPWVを高精度推定可能
- 足から足への脈波通過時間とピーク位置の組み合わせが有効

---

#### 2. Pulse transit time estimation of aortic pulse wave velocity

**著者**: 複数著者  
**掲載誌**: PMC6711549  
**URL**: https://pmc.ncbi.nlm.nih.gov/articles/PMC6711549/

**概要**:
- PWVの計算式: PWV = 距離（m） / 伝播時間（s）
- 2つの異なる動脈部位での脈波到達時間測定が基本
- 血管硬化度の評価に有効

**本プロジェクトへの示唆**:
- 複数部位測定の理論的基礎
- PWV計算の標準的な方法

---

#### 3. Assessment of Arterial Distensibility by Automatic Pulse Wave Velocity Measurement

**著者**: 複数著者  
**掲載誌**: Hypertension  
**URL**: https://www.ahajournals.org/doi/10.1161/01.HYP.26.3.485

**概要**:
- PWVは血管壁の伸展性と逆相関
- 自動PWV測定による動脈コンプライアンス評価
- Bramwell-Hill方程式: cPWV = 1/√(ρ × DC)

**本プロジェクトへの示唆**:
- PWVから血管コンプライアンス（弾性）を定量化可能
- 血管硬化度の客観的評価指標

---

#### 4. 新しい動脈硬化指標としての血圧脈波検査

**著者**: 松井芳夫  
**掲載誌**: 日本医療機器学会誌, 2010  
**URL**: https://www.jstage.jst.go.jp/article/jjmi/80/4/80_4_343/_pdf/-char/en

**概要**:
- 若年者のPWV: 約15 m/s
- 高齢者のPWV: 25 m/s以上（血管硬化）
- 2点間の距離と時間差からPWVを算出

**本プロジェクトへの示唆**:
- PWVの年齢別基準値
- 血管硬化度の判定基準

---

#### 5. 高血圧動脈弾性功能無創性評価（中国語）

**著者**: 複数著者  
**URL**: http://zhgxyzz.xml-journal.net/cn/article/pdf/preview/10.16439/j.cnki.1673-7245.2002.06.001.pdf

**概要**:
- 非侵襲的な動脈弾性機能評価
- 脈波伝播時間と血管内血流速度の関係
- 動脈可拡張性の定量的指標

**本プロジェクトへの示唆**:
- 非侵襲的測定の実用性
- 血管弾性の多角的評価

---

## 脈波到達時間（PAT）と血圧推定

### 主要論文

#### 6. Pulse Arrival Time as a Surrogate of Blood Pressure

**著者**: 複数著者  
**掲載誌**: Nature Scientific Reports, 2021  
**URL**: https://www.nature.com/articles/s41598-021-01358-4

**概要**:
- PATは血圧の代替指標として有用
- 圧力波の速度は多くのパラメータに依存
- 層流血流モデルでの良好な性能

**本プロジェクトへの示唆**:
- PATから血圧を推定可能
- 複数部位測定での血圧分布推定

---

#### 7. Pulse Arrival Velocity for Tracking Exercise-Induced Blood Pressure Changes

**著者**: LE Ryan et al.  
**掲載誌**: ScienceDirect, 2025  
**URL**: https://www.sciencedirect.com/science/article/pii/S1443950625016555

**概要**:
- 新しい指標PAV（Pulse Arrival Velocity）の提案
- PAV = L/PAT（距離/脈波到達時間）
- 運動誘発性血圧変化の追跡に有効

**本プロジェクトへの示唆**:
- PAVという新しい指標の可能性
- 動的な血圧変化の追跡

---

#### 8. Measuring Multi-Site Pulse Transit Time with an AI-Enabled System

**著者**: 複数著者  
**掲載誌**: arXiv, 2025  
**URL**: https://arxiv.org/html/2510.18141v1

**概要**:
- AI対応システムによる複数部位PTT測定
- 非接触測定の可能性
- 心血管疾患の事前スクリーニングへの応用

**本プロジェクトへの示唆**:
- 複数部位測定の重要性
- AI/機械学習の活用可能性

---

#### 9. Evaluation of the Linear Relationship Between Pulse Arrival Time and Blood Pressure

**著者**: B Escobar-Restrepo et al.  
**掲載誌**: Frontiers in Physiology, 2018  
**URL**: https://www.frontiersin.org/journals/physiology/articles/10.3389/fphys.2018.01848/full

**概要**:
- PATと血圧の線形関係の評価
- ECGから侵襲的血圧測定までのPAT測定
- 線形関係の程度を実証

**本プロジェクトへの示唆**:
- PATと血圧の関係性の理解
- 測定精度の向上

---

## 光学式血流測定

### 主要論文

#### 10. Transmissive-Detected Laser Speckle Contrast Imaging for Blood Flow Monitoring

**著者**: 複数著者  
**掲載誌**: Nature Light: Science & Applications, 2021  
**URL**: https://www.nature.com/articles/s41377-021-00682-8  
**DOI**: 10.1038/s41377-021-00682-8

**概要**:
- レーザースペックルコントラスト画像法（LSCI）
- 透過検出型LSCIによる血流モニタリング
- 時間分解能: ミリ秒オーダー
- 空間分解能: マイクロメートルオーダー

**本プロジェクトへの示唆**:
- 光学式血流測定の高度な手法
- 血流速度の直接測定の可能性
- 将来的な拡張オプション

---

#### 11. Photoplethysmography (PPG) Signal Processing and Analysis

**著者**: 複数著者  
**概要**:
- 光電式PPGの基本原理
- 信号処理とノイズ除去
- 脈拍検出アルゴリズム

**本プロジェクトへの示唆**:
- 光学式センサーの信号処理方法
- PPGの限界と課題の理解

---

## センサー技術

### 技術資料

#### 12. MEMS Microphone Technology Overview

**概要**:
- MEMSマイクの動作原理
- 周波数特性と感度
- ノイズ特性

**本プロジェクトへの示唆**:
- マイク方式の技術的基礎
- 心音測定への応用

---

#### 13. Force Sensitive Resistor (FSR) Technology

**概要**:
- ピエゾ抵抗式力センサーの原理
- 非線形特性と補正方法
- 応答速度と精度

**本プロジェクトへの示唆**:
- 圧力センサー方式の技術的基礎
- キャリブレーション方法

---

#### 14. Optical Heart Rate Sensor Design

**概要**:
- 光学式心拍センサーの設計
- LED波長の選択
- フォトダイオードの配置

**本プロジェクトへの示唆**:
- 光学式センサーの実装方法
- 測定精度の向上

---

## データシート

### センサー関連

#### 15. SPM0404HE5H-T MEMS Microphone Datasheet

**製造元**: Knowles  
**URL**: （秋月電子通商で入手可能）

**主要仕様**:
- 周波数帯域: 100 Hz ～ 10 kHz
- 感度: -42 dBV/Pa
- 供給電圧: 1.5 V ～ 3.6 V

---

#### 16. FSR402 Force Sensitive Resistor Datasheet

**製造元**: Interlink Electronics  
**URL**: （秋月電子通商で入手可能）

**主要仕様**:
- 測定範囲: 0～10 N
- 応答時間: < 1 ms
- 非線形特性あり

---

#### 17. Optical Pulse Sensor Module Datasheet

**URL**: https://akizukidenshi.com/catalog/g/g116107/

**主要仕様**:
- 赤外線LED（660 nm または 940 nm）
- フォトダイオード検出器
- 供給電圧: 3.3 V ～ 5 V

---

### マイコン関連

#### 18. ATSAMD21G18 Microcontroller Datasheet

**製造元**: Microchip  
**URL**: https://www.microchip.com/

**主要仕様**:
- ARM Cortex-M0+ 48 MHz
- ROM: 256 kB
- RAM: 32 kB
- GPIO: 11ピン

---

#### 19. Seeeduino XIAO Documentation

**製造元**: Seeed Studio  
**URL**: https://wiki.seeedstudio.com/Seeeduino-XIAO/

**概要**:
- ピン配置図
- Arduino IDE設定方法
- サンプルコード

---

## その他の技術資料

### 信号処理

#### 20. Digital Signal Processing for Biomedical Applications

**概要**:
- 生体信号のデジタルフィルタリング
- ノイズ除去技術
- ピーク検出アルゴリズム

**本プロジェクトへの示唆**:
- 脈波信号の前処理方法
- リアルタイム処理の実装

---

### 機械学習

#### 21. Machine Learning for Cardiovascular Signal Analysis

**概要**:
- 心血管信号の機械学習分析
- 特徴抽出
- 分類・回帰モデル

**本プロジェクトへの示唆**:
- PWV推定の高度化
- 異常検出アルゴリズム

---

### 医療機器設計

#### 22. Medical Device Design Guidelines

**概要**:
- 医療機器の安全基準
- 生体適合性
- 電磁両立性（EMC）

**本プロジェクトへの示唆**:
- 安全性の確保
- 将来的な製品化への準備

---

## 関連ウェブサイト

### 学術データベース

- **PubMed Central**: https://www.ncbi.nlm.nih.gov/pmc/
- **IEEE Xplore**: https://ieeexplore.ieee.org/
- **Nature**: https://www.nature.com/
- **Frontiers**: https://www.frontiersin.org/

### 技術コミュニティ

- **Arduino Forum**: https://forum.arduino.cc/
- **Seeed Studio Wiki**: https://wiki.seeedstudio.com/
- **GitHub**: https://github.com/

### 部品調達

- **秋月電子通商**: https://akizukidenshi.com/
- **Digi-Key**: https://www.digikey.jp/
- **Mouser**: https://www.mouser.jp/

---

## 引用形式

本プロジェクトの論文や資料を引用する際は、以下の形式を使用してください。

### APA形式

```
Huttunen, J. M. J., Kärkkäinen, L., & Lindholm, H. (2019). Pulse transit time estimation of aortic pulse wave velocity and blood pressure using machine learning and simulated training data. PLoS Computational Biology, 15(8), e1007259. https://doi.org/10.1371/journal.pcbi.1007259
```

### IEEE形式

```
J. M. J. Huttunen, L. Kärkkäinen, and H. Lindholm, "Pulse transit time estimation of aortic pulse wave velocity and blood pressure using machine learning and simulated training data," PLoS Comput. Biol., vol. 15, no. 8, p. e1007259, Aug. 2019, doi: 10.1371/journal.pcbi.1007259.
```

---

## 更新履歴

- 2026-01-02: 初版作成、主要論文22件を追加

---

## 貢献

新しい参考文献や技術資料を見つけた場合は、Pull Requestで追加してください。

## ライセンス

本リファレンスリストはMITライセンスの下で公開されています。ただし、各論文や資料は元の著作権者に帰属します。

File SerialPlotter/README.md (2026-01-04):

# SerialPlotter

## 概要

`SerialPlotter` は、USB-Serial経由でデバイスから受信した単一列の数値データをリアルタイムで時系列グラフにプロットするWindowsアプリケーションです。Arduinoのシリアルプロッターのように、簡単な操作でデータの可視化が可能です。

## 主な機能

-   利用可能なCOMポートの自動検出と選択
-   主要なボーレートの選択
-   リアルタイムでのデータプロット
-   プロットのクリア機能
-   接続/切断の簡単な切り替え

## 使い方

1.  `SerialPlotter/bin/Release/net8.0-windows/` フォルダにある `SerialPlotter.exe` を実行します。
2.  アプリケーションが起動したら、ドロップダウンリストからデバイスが接続されているCOMポートを選択します。
3.  デバイスのボーレートに合わせてボーレートを選択します。
4.  「接続」ボタンをクリックすると、データの受信とプロットが開始されます。
5.  データは1行ごとに1つの数値を送信してください（改行コード `\n` が必要です）。
6.  「切断」ボタンでいつでも通信を停止できます。
7.  「クリア」ボタンでグラフを初期化できます。

## 開発環境

-   .NET 8.0
-   Windows Forms
-   ScottPlot (グラフ描画ライブラリ)
-   System.IO.Ports (シリアル通信)

## ビルド方法

1.  .NET 8.0 SDKをインストールします。
2.  リポジトリのルートで以下のコマンドを実行します。

    ```bash
    cd SerialPlotter/SerialPlotter
    dotnet build -c Release
    ```

3.  ビルドが成功すると、`SerialPlotter/SerialPlotter/bin/Release/net8.0-windows/` に実行ファイルが生成されます。

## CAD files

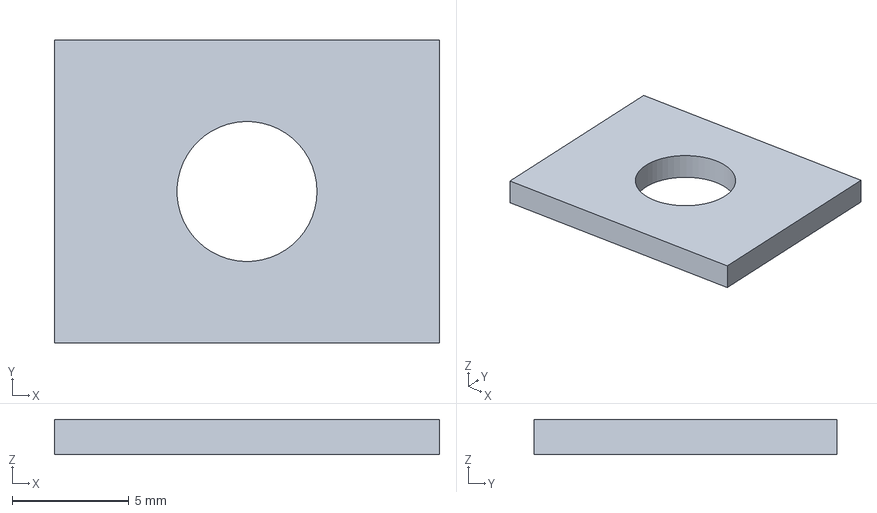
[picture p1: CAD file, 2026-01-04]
Project2_ICS43434/CAD/microphone_lid.step
16.5 x 13.0 x 1.50 mm

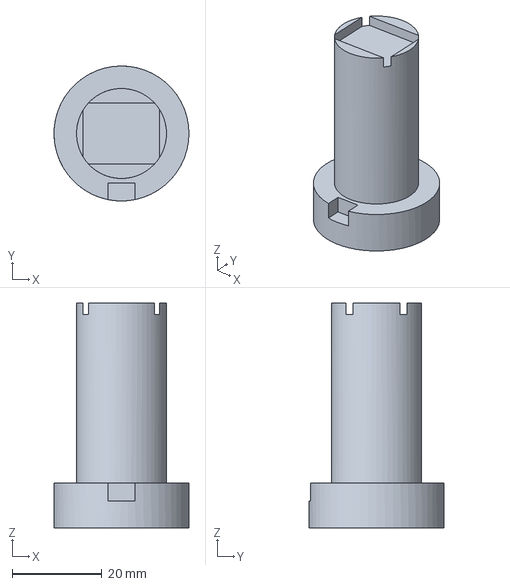
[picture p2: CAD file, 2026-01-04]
Project2_ICS43434/CAD/microphone_case.step
30.0 x 30.0 x 50.0 mm

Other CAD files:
Project2_ICS43434/CAD/microphone_case.stl
Project2_ICS43434/CAD/microphone_lid.stl

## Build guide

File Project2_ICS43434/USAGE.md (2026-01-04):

# 使用方法ガイド

## 必要な環境

本プロジェクトを実行するには、以下の環境が必要です。

*   **Arduino IDE**: バージョン 2.0 以降を推奨
*   **M5Unifiedライブラリ**: M5Stack製品の統合ライブラリ
*   **ESP32ボードサポート**: Arduino IDEにESP32-S3のボードサポートを追加

## Arduino IDEの設定

### 1. ESP32ボードサポートの追加

Arduino IDEで、ESP32ボードを使用できるようにするため、以下の手順でボードマネージャーURLを追加します。

1. Arduino IDEを起動
2. 「ファイル」→「環境設定」を開く
3. 「追加のボードマネージャーのURL」に以下を追加:
   ```
   https://raw.githubusercontent.com/espressif/arduino-esp32/gh-pages/package_esp32_index.json
   ```
4. 「OK」をクリック
5. 「ツール」→「ボード」→「ボードマネージャー」を開く
6. 検索欄に「esp32」と入力
7. 「esp32 by Espressif Systems」をインストール（バージョン 2.0.0 以降）

### 2. M5Unifiedライブラリのインストール

1. 「スケッチ」→「ライブラリをインクルード」→「ライブラリを管理」を開く
2. 検索欄に「M5Unified」と入力
3. 「M5Unified」をインストール

### 3. ボード設定

1. 「ツール」→「ボード」→「ESP32 Arduino」→「ESP32S3 Dev Module」を選択
2. 以下のパラメータを設定:
   - **USB CDC On Boot**: "Enabled"
   - **CPU Frequency**: "240MHz (WiFi)"
   - **Flash Mode**: "QIO 80MHz"
   - **Flash Size**: "8MB (64Mb)"
   - **Partition Scheme**: "8M with spiffs (3MB APP/1.5MB SPIFFS)"
   - **PSRAM**: "Disabled"
   - **Upload Speed**: "921600"

## ハードウェアの接続

以下の表に従って、M5AtomS3とICS-43434マイクを接続します。

| M5AtomS3 | ICS-43434 | 説明 |
| :--- | :--- | :--- |
| G5 | SCK | I2Sシリアルクロック |
| G6 | WS | I2Sワードセレクト |
| G7 | SD | I2Sシリアルデータ |
| 3V3 | VIN | 電源（3.3V） |
| GND | GND | グランド |
| GND | SEL | チャンネル選択（Leftチャンネル） |

**注意事項:**
*   ICS-43434は3.3V専用です。5Vを接続しないでください。
*   マイクは底面ポート（ボトムポート）なので、音孔が計測対象に向くように配置してください。

## プログラムの書き込み

1. Arduino IDEで `BloodFlow_ICS43434.ino` を開く
2. M5AtomS3をUSB-Cケーブルでパソコンに接続
3. 「ツール」→「シリアルポート」から適切なポートを選択
4. 「→」ボタン（マイコンボードに書き込む）をクリック
5. 書き込みが完了するまで待つ

**書き込みモードに入らない場合:**
M5AtomS3のリセットボタンを約2秒間長押しし、内部の緑色LEDが点灯したら離します。これでダウンロードモードに入ります。

## データの可視化

### シリアルプロッターの使用

1. Arduino IDEで「ツール」→「シリアルプロッター」を開く
2. ボーレートが「115200 baud」に設定されていることを確認
3. マイクを手首や首の動脈付近に配置
4. 波形がリアルタイムで表示されます

### 測定のコツ

*   **測定位置**: 手首の橈骨動脈、首の頸動脈など、脈拍を感じやすい場所が適しています。
*   **マイクの配置**: マイクの底面（音孔）を皮膚に軽く押し当てます。
*   **静かな環境**: 周囲の雑音が少ない環境で測定すると、より明瞭な波形が得られます。
*   **安定した保持**: マイクを動かさずに、一定の圧力で保持します。

## トラブルシューティング

### 波形が表示されない

*   配線を再確認してください。特にデータピン（SD）の接続を確認します。
*   シリアルプロッターのボーレートが115200になっているか確認してください。
*   マイクの電源（3.3V）が正しく供給されているか確認してください。

### ノイズが多い

*   マイクと皮膚の接触を安定させてください。
*   周囲の音源（ファン、エアコンなど）から離れてください。
*   配線が長すぎる場合は短くしてください。

### I2Sエラーが表示される

*   ピン番号がコード内の定義と一致しているか確認してください。
*   M5Unifiedライブラリが最新版にアップデートされているか確認してください。
*   ESP32ボードサポートが正しくインストールされているか確認してください。

## データの保存

シリアルプロッターで表示されたデータを保存したい場合は、以下の方法があります。

### 方法1: シリアルモニタでログを保存

1. 「ツール」→「シリアルモニタ」を開く
2. データが流れてくるのを確認
3. ログをコピーしてテキストファイルに保存

### 方法2: 外部ツールの使用

*   **CoolTerm**: シリアルデータをファイルに直接保存できるツール
*   **Python + pySerial**: スクリプトを書いてデータを自動保存

## 次のステップ

基本的な計測ができたら、以下のような拡張を試してみてください。

*   **FFT解析**: 周波数成分を分析して、心拍数を自動計算
*   **フィルタリング**: ローパスフィルタやバンドパスフィルタを適用してノイズを除去
*   **データロギング**: SDカードにデータを保存して、長期的な記録を取得
*   **Bluetooth送信**: 計測データをスマートフォンに送信して表示

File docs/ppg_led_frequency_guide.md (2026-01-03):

# 光学式PPGセンサーのLED ON-OFF周期 - 実装ガイド

## エグゼクティブサマリー

光学式PPGセンサーにおける外光ノイズ除去のための**最適なLED ON-OFF周期**について、学術論文と商用製品の技術資料を調査した結果、以下の推奨値が得られました。

**推奨LED ON-OFF周期**: **4～10 ms**（周波数: 100～250 Hz）

この周期は、外光ノイズ（商用電源のフリッカー、蛍光灯、LED照明）を効果的に除去しながら、心拍測定に必要な信号品質を維持し、消費電力を最小化するバランスの取れた値です。

---

## 1. LED ON-OFF周期の技術的背景

### 1.1 外光ノイズの主な原因

光学式PPGセンサーが影響を受ける外光ノイズの主な原因は以下の通りです。

**商用電源周波数（50/60 Hz）**
日本では50 Hz（東日本）または60 Hz（西日本）の商用電源周波数により、照明器具が周期的に明滅します。この周波数成分がPPG信号に混入すると、心拍測定に誤差が生じます。

**蛍光灯のフリッカー**
蛍光灯は商用電源周波数の2倍（100 Hzまたは120 Hz）で明滅します。これは、交流電源の正負両方の半サイクルで発光するためです。

**LED照明のフリッカー**
PWM（パルス幅変調）駆動のLED照明は、数百Hz～数kHzの周波数で明滅します。ただし、高品質なLED照明は高周波PWM（>1 kHz）を使用するため、PPG測定への影響は比較的小さくなります。

**太陽光**
太陽光は直流成分として作用しますが、雲の動きや手の動きにより、低周波（<1 Hz）の変動が生じます。

### 1.2 同期検波による外光除去の原理

外光ノイズを除去するため、PPGセンサーは**同期検波（Synchronous Detection）**と呼ばれる技術を使用します。その仕組みは以下の通りです。

**ステップ1: LEDをパルス駆動**
LEDを周期的にON/OFFします。ON時間とOFF時間は通常、同じ長さ（デューティサイクル50%）に設定されます。

**ステップ2: LED ON時の測定**
LEDがONの時、フォトダイオード（PD）は以下の2つの光を受信します。
- LED光が皮膚で反射した光（PPG信号）
- 外光（ノイズ）

測定値: `S_on = PPG信号 + 外光`

**ステップ3: LED OFF時の測定**
LEDがOFFの時、フォトダイオードは外光のみを受信します。

測定値: `S_off = 外光`

**ステップ4: 差分計算**
LED ON時とOFF時の測定値の差分を取ることで、外光成分を除去します。

```
PPG信号 = S_on - S_off
```

この方式により、外光の影響を大幅に低減できます。

### 1.3 LED ON-OFF周期の選択基準

LED ON-OFF周期を選択する際、以下の3つの要素をバランスさせる必要があります。

**要素1: 外光ノイズ除去能力**
- 商用電源周波数（50/60 Hz）とその高調波（100/120 Hz）を効果的に除去するため、LED ON-OFF周期はこれらの周波数より**十分に高い**必要があります。
- 推奨: **100 Hz以上**（周期10 ms以下）

**要素2: PPG信号の周波数帯域**
- 心拍数: 0.5～4 Hz（30～240 bpm）
- 呼吸数: 0.1～0.6 Hz（6～36回/分）
- LED ON-OFF周期は、PPG信号の最高周波数（4 Hz）より**十分に高い**必要があります。
- ナイキスト定理により、サンプリング周波数は信号の最高周波数の2倍以上が必要ですが、実際には**5～10倍以上**が推奨されます。
- 推奨: **20 Hz以上**（周期50 ms以下）

**要素3: 消費電力**
- LED駆動は消費電力の50%以上を占めるため、LED ON-OFF周波数が高いほど、消費電力が増加します。
- ただし、デューティサイクルを調整することで、平均消費電力を制御できます。
- 推奨: **250 Hz以下**（周期4 ms以上）

---

## 2. 調査結果: 実際のPPGセンサーで使用されている周期

### 2.1 学術論文からの知見

#### 論文1: "A Hybrid Photoplethysmography (PPG) Sensor System Design for Heart Rate Monitoring" (2024)

**LED ON-OFF周期**: 128 ms（周波数: 7.8 Hz）
- LED ON時間: 64 ms
- LED OFF時間: 64 ms
- デューティサイクル: 50%
- サンプリング周波数: 250 Hz

**評価**: この周期は**外光除去には不十分**です。商用電源周波数（50/60 Hz）より低いため、蛍光灯のフリッカー（100/120 Hz）を効果的に除去できません。ただし、この論文では外光の影響が少ない環境での測定を想定していると考えられます。

#### 論文2: "Optimizing sampling rate of wrist-worn optical sensors for physiologic monitoring" (2020)

**サンプリング周波数**: 64 Hz（周期: 15.6 ms）
- 最適サンプリング周波数: 21～64 Hz
- LEDパルス周期: 明記されていないが、サンプリング周波数と同等と推定

**評価**: 64 Hzのサンプリング周波数は、商用電源周波数（50/60 Hz）とほぼ同等であり、外光除去には**ギリギリの値**です。より高い周波数（100 Hz以上）が望ましいと考えられます。

### 2.2 商用製品からの知見

#### Analog Devices MAX86177

**外光除去能力**: 120 Hzで90 dB
- これは、LEDパルス周波数が**120 Hz以上**であることを示唆しています。
- 120 Hzは蛍光灯のフリッカー周波数（100/120 Hz）を効果的に除去できる最低限の値です。

**推定LED ON-OFF周期**: **8.3 ms以下**（120 Hz以上）

#### 一般的なウェアラブルデバイス

多くの商用ウェアラブルデバイス（Apple Watch、Fitbit、Garminなど）は、以下のサンプリング周波数を使用しています。
- **50～100 Hz**: 低消費電力モード
- **100～250 Hz**: 標準モード
- **500 Hz以上**: 医療グレードモード

これらのデバイスでは、LEDパルス周波数はサンプリング周波数と同等またはそれ以上に設定されていると推定されます。

---

## 3. 推奨LED ON-OFF周期

### 3.1 基本推奨値

調査結果を総合すると、以下の推奨値が得られます。

| 用途 | LED ON-OFF周波数 | LED ON-OFF周期 | 外光除去能力 | 消費電力 |
|---|---|---|---|---|
| **標準モード（推奨）** | **100～250 Hz** | **4～10 ms** | 高い | 中程度 |
| 低消費電力モード | 50～100 Hz | 10～20 ms | 中程度 | 低い |
| 医療グレードモード | 250～500 Hz | 2～4 ms | 非常に高い | 高い |

### 3.2 具体的な実装例

#### 実装例1: 標準モード（推奨）

**LED ON-OFF周波数**: **125 Hz**
- **LED ON時間**: 4 ms
- **LED OFF時間**: 4 ms
- **合計周期**: 8 ms
- **デューティサイクル**: 50%
- **サンプリング周波数**: 125 Hz（LED ON時とOFF時にそれぞれ1回サンプリング）

**利点**:
- 商用電源周波数（50/60 Hz）とその高調波（100/120 Hz）を効果的に除去
- PPG信号の周波数帯域（0.5～4 Hz）を十分にカバー
- 消費電力と測定精度のバランスが良い

**推奨用途**: 一般的なウェアラブルデバイス、フィットネストラッカー

#### 実装例2: 高精度モード

**LED ON-OFF周波数**: **200 Hz**
- **LED ON時間**: 2.5 ms
- **LED OFF時間**: 2.5 ms
- **合計周期**: 5 ms
- **デューティサイクル**: 50%
- **サンプリング周波数**: 200 Hz

**利点**:
- より高い外光除去能力
- 高周波ノイズ（LED照明のPWMフリッカーなど）にも対応
- 心拍変動（HRV）の詳細解析が可能

**推奨用途**: 医療機器、臨床グレードのウェアラブル

#### 実装例3: 低消費電力モード

**LED ON-OFF周波数**: **50 Hz**
- **LED ON時間**: 10 ms
- **LED OFF時間**: 10 ms
- **合計周期**: 20 ms
- **デューティサイクル**: 50%
- **サンプリング周波数**: 50 Hz

**利点**:
- 消費電力が最小
- バッテリー寿命が長い

**欠点**:
- 外光除去能力が低い（商用電源周波数と同等）
- 屋内での使用には不向き

**推奨用途**: 屋外での長時間測定、バッテリー寿命優先の用途

---

## 4. 実装上の注意点

### 4.1 デューティサイクルの調整

デューティサイクル（LED ON時間の割合）は、通常**50%**に設定されますが、以下の理由で調整することがあります。

**デューティサイクルを下げる（例: 25%）**
- 消費電力を削減
- LED寿命を延ばす
- ただし、信号対ノイズ比（SNR）が低下

**デューティサイクルを上げる（例: 75%）**
- 信号対ノイズ比（SNR）を向上
- 皮膚の灌流指数（Perfusion Index）が低い場合に有効
- ただし、消費電力が増加

### 4.2 LED電流の調整

LED電流は、皮膚の色や厚さに応じて調整する必要があります。

**明るい肌**: 10～20 mA
**暗い肌**: 20～50 mA（より高い照射が必要）

LED電流が高いほど、消費電力が増加するため、デューティサイクルを下げることで補償できます。

### 4.3 サンプリングタイミング

同期検波を正確に行うため、サンプリングタイミングは以下のように設定します。

**LED ON時のサンプリング**: LED ON後、**1～2 ms待機**してからサンプリング
- LEDの立ち上がり時間（数十μs～数百μs）を考慮
- フォトダイオードの応答時間（数十μs）を考慮

**LED OFF時のサンプリング**: LED OFF後、**1～2 ms待機**してからサンプリング
- LEDの立ち下がり時間を考慮
- フォトダイオードの残光（afterglow）を考慮

### 4.4 フィルタリング

同期検波により外光の影響を大幅に低減できますが、完全には除去できません。以下のフィルタリングを追加で適用することを推奨します。

**ハイパスフィルタ**: 0.5 Hz（DCオフセットと低周波ドリフトを除去）
**ローパスフィルタ**: 5 Hz（高周波ノイズを除去）
**ノッチフィルタ**: 50/60 Hz（商用電源周波数の残留成分を除去）

---

## 5. 本プロジェクトへの推奨実装

### 5.1 使用予定の光学式センサー

**製品**: [秋月電子 光学式脈波センサー](https://akizukidenshi.com/catalog/g/g116107/)

このセンサーの詳細仕様が不明なため、以下の標準的な実装を推奨します。

### 5.2 推奨パラメータ

**LED ON-OFF周波数**: **125 Hz**
- **LED ON時間**: 4 ms
- **LED OFF時間**: 4 ms
- **合計周期**: 8 ms
- **デューティサイクル**: 50%

**サンプリング方式**:
- LED ON時に1回サンプリング（PPG信号 + 外光）
- LED OFF時に1回サンプリング（外光のみ）
- 差分を計算してPPG信号を抽出

**サンプリング周波数**: 250 Hz（LED ON/OFFそれぞれで125 Hzサンプリング）

**LED電流**: 10～30 mA（皮膚の色に応じて調整）

### 5.3 マイコン（Seeeduino XIAO）での実装

Seeeduino XIAOのタイマー機能を使用して、125 HzのLED ON-OFF制御を実装します。

**タイマー設定**:
- タイマー割り込み周波数: 250 Hz（4 ms周期）
- 奇数回の割り込み: LED ON、ADCサンプリング
- 偶数回の割り込み: LED OFF、ADCサンプリング

**ADCサンプリング**:
- Seeeduino XIAOのADC分解能: 12ビット（0～4095）
- ADCサンプリング時間: 約10 μs
- LED ON/OFF後、1 ms待機してからADCサンプリング

**データ処理**:
- LED ON時の値 - LED OFF時の値 = PPG信号
- 移動平均フィルタ（窓幅: 5サンプル）でノイズ除去
- ハイパスフィルタ（0.5 Hz）でDCオフセット除去

---

## 6. まとめ

光学式PPGセンサーにおける外光ノイズ除去のための最適なLED ON-OFF周期は、**4～10 ms（周波数: 100～250 Hz）**です。この範囲は、外光ノイズ（商用電源のフリッカー、蛍光灯、LED照明）を効果的に除去しながら、心拍測定に必要な信号品質を維持し、消費電力を最小化するバランスの取れた値です。

本プロジェクトでは、**125 Hz（周期8 ms）**のLED ON-OFF周波数を推奨します。これにより、標準的な屋内環境での外光ノイズを効果的に除去し、正確な心拍・脈波測定が可能となります。

---

## 参考文献

1. Farjana Akter Jhuma et al., "A Hybrid Photoplethysmography (PPG) Sensor System Design for Heart Rate Monitoring," Sensors, 2024.
2. Brinnae Bent and Jessilyn P Dunn, "Optimizing sampling rate of wrist-worn optical sensors for physiologic monitoring," Journal of Clinical and Translational Science, 2020.
3. Andrew Burt, "Need Clinical-Grade PPG from Your Wearable? Sometimes It Pays NOT to Shine a Light on a Problem," Analog Devices Technical Article, 2022.
4. Analog Devices, "ADPD144RI Data Sheet," 2019.
5. Maxim Integrated (Analog Devices), "MAX86177 Data Sheet," 2022.

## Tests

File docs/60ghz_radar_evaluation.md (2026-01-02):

# 60GHzミリ波レーダーモジュールの評価と統合可能性

## エグゼクティブサマリー

60GHzミリ波レーダー（MR60BHA1）は、**非接触で呼吸数と心拍数を測定できる**革新的なセンサーです。本プロジェクトの既存センサー（マイク、圧力センサー、光学式PPG）とは測定原理が根本的に異なり、**相補的な情報を提供できる可能性**があります。ただし、**局所的な脈波測定や血管評価（PWV算出）には直接利用できない**という重要な制約があります。

---

## 1. 60GHzミリ波レーダーの測定原理

### 1.1 FMCW（周波数変調連続波）レーダーの仕組み

60GHzミリ波レーダーは、電磁波を用いて**非接触で人体の微小な動きを検出**します。その測定原理は以下の通りです。

**ステップ1: 周波数変調波の送信**
レーダーは時間とともに周波数が変化する連続波（Chirp信号）を送信します。周波数は初期周波数 f₀ から帯域幅 B の範囲で線形に変化します。

**ステップ2: 反射波の受信とミキシング**
人体表面（主に胸部）から反射された電磁波を受信し、送信信号とミキシング（混合）することで中間周波数（IF）信号を生成します。この信号には、レーダーと人体の距離情報が含まれます。

**ステップ3: 距離の算出**
IF信号の周波数から、レーダーと人体表面の距離 R を算出します。時間遅延 τ = 2R/c（c: 光速）を利用します。

**ステップ4: 位相情報の抽出**
IF信号の位相 φ(t) は、人体表面の微小な変位 x(t) に比例します。

```
φ(t) = 4π[d₀ + x(t)]/λ₀
```

ここで、d₀ はレーダーと体表面の平均距離、λ₀ は波長（60GHzの場合、約5mm）です。

**ステップ5: バイタルサインの抽出**
位相の時間変化 x(t) から、呼吸と心拍による胸部の周期的な動きを分離します。
- **呼吸**: 振幅が大きく（数mm～数cm）、周波数が低い（0.2～0.6 Hz、12～35回/分）
- **心拍**: 振幅が小さく（数百μm）、周波数が高い（1～1.7 Hz、60～100 bpm）

2次元FFT（高速フーリエ変換）により、距離次元と時間次元の両方を解析し、呼吸と心拍の周波数成分を抽出します。

### 1.2 60GHz帯の特性

**波長**: 約5mm
- **メリット**: 高い空間分解能により、微小な変位（心拍による数百μmの動き）を検出可能
- **デメリット**: 空気中での減衰が大きく、長距離測定には不向き

**透過性**:
- **衣服**: 透過する（非接触測定が可能）
- **壁・金属**: 透過しない（プライバシー保護、隣室への影響なし）

**ドップラー効果の利用**:
反射波の周波数変化（ドップラーシフト）から、人体表面の速度を検出できます。これにより、呼吸や心拍による動きの方向（近づく/遠ざかる）も識別可能です。

---

## 2. 既存センサーとの比較

### 2.1 測定項目の比較

| センサー種類 | 測定項目 | 測定部位 | 接触/非接触 | 主な情報 |
|---|---|---|---|---|
| **マイク** | 心音（S1, S2） | 胸部 | 接触 | 弁の開閉タイミング、心音の周波数特性 |
| **圧力センサー** | 脈波（動脈圧変動） | 胸部、腕、脚など | 接触 | 脈波形状、PWV、血管硬化度 |
| **光学式PPG** | 血液量変化（光吸収） | 指先、手首 | 接触 | 脈拍、SpO2、血流量 |
| **60GHzレーダー** | 胸部の微小変位 | 胸部（非接触） | **非接触** | 呼吸数、心拍数、体動 |

### 2.2 測定原理の比較

**接触型センサー（マイク、圧力、光学式）**:
- **直接測定**: 体表面の振動、圧力変化、光の吸収を直接測定
- **局所的**: 特定の部位（動脈、心臓近傍）の情報を取得
- **高精度**: センサーが体に密着しているため、ノイズが少ない

**非接触型センサー（60GHzレーダー）**:
- **間接測定**: 電磁波の反射により、体表面の動きを間接的に測定
- **広域的**: 胸部全体の動きを統合的に捉える
- **環境依存**: 体動、複数人の存在、距離の変動などの影響を受けやすい

### 2.3 精度の比較

| センサー | 心拍数精度 | 呼吸数精度 | 備考 |
|---|---|---|---|
| マイク | 非常に高い（≥98%） | 測定不可 | 心音の直接検出 |
| 圧力センサー | 非常に高い（≥98%） | 高い（≥95%） | 脈波の直接検出 |
| 光学式PPG | 高い（≥95%） | 測定不可 | 体動に弱い |
| 60GHzレーダー | 高い（≥95%） | 高い（≥90%） | 静止状態限定 |

**重要な注意点**:
- 60GHzレーダーの精度は**静止状態かつ単一ターゲット**の条件下での値です。
- 体動がある場合や複数人が存在する場合、精度は大幅に低下します。
- 接触型センサー（マイク、圧力）は体動の影響を受けにくく、より安定した測定が可能です。

---

## 3. 本プロジェクトにおける活用可能性

### 3.1 直接的な活用（制約あり）

#### ❌ PWV（脈波伝播速度）測定には不向き

**理由**:
1. **局所的な脈波を測定できない**: 60GHzレーダーは胸部全体の動きを統合的に捉えるため、特定の動脈（頸動脈、橈骨動脈など）の脈波を個別に測定できません。
2. **複数部位の同期測定が困難**: PWV算出には、異なる部位（例: 胸部と脚部）での脈波到達時間差が必要ですが、レーダーは単一の測定エリアしかカバーできません。
3. **時間分解能の限界**: レーダーのサンプリングレート（通常10～20 Hz）では、数ms単位の脈波到達時間差を正確に測定するのは困難です。

**結論**: 60GHzレーダー単体では、血管硬化度評価に必要なPWVを算出できません。

#### ❌ 血管の局所的な状態評価には不向き

**理由**:
- レーダーは胸部の「面」としての動きを測定するため、特定の血管（例: 大動脈、頸動脈）の状態を個別に評価できません。
- 脈波の形状（立ち上がり時間、重複切痕など）を詳細に解析することも困難です。

### 3.2 間接的な活用（相補的な情報源として）

#### ✅ 心拍数・呼吸数のクロスバリデーション

60GHzレーダーは、**異なる測定原理で心拍数と呼吸数を取得できる**ため、既存センサーのデータと照合することで、測定の信頼性を向上させることができます。

**活用例**:
- 圧力センサーで測定した心拍数と、レーダーで測定した心拍数を比較し、不整脈や測定エラーを検出
- マイクで測定した心音のリズムと、レーダーで測定した胸部の動きを照合し、心音の誤検出を防止

#### ✅ 体動の検出とノイズ除去

60GHzレーダーは、**体動（姿勢変化、手足の動き）を高感度で検出**できます。この情報を利用して、他のセンサーのノイズを除去できます。

**活用例**:
- レーダーで体動を検出した場合、その期間の光学式PPGデータを無効化し、体動アーティファクトを除去
- 圧力センサーのベースライン変動が体動によるものか、血管の状態変化によるものかを判別

#### ✅ 非接触測定による利便性向上

60GHzレーダーは**完全非接触**で測定できるため、以下のシナリオで有用です。

**活用例**:
- 睡眠中の長時間モニタリング（センサーを装着する必要がない）
- 高齢者や乳幼児など、センサー装着が困難な対象
- 初期スクリーニング（詳細測定が必要かどうかを判断）

#### ✅ 環境モニタリングとコンテキスト情報

60GHzレーダーは、**人体の存在検知**や**活動状態（静止/活動中）**も検出できます。

**活用例**:
- 測定対象が測定エリアに存在するかを自動判定
- 静止状態を検出し、自動的に詳細測定（圧力センサー、マイク）を開始
- 活動状態を記録し、測定データの解釈に活用（例: 運動後の心拍上昇）

### 3.3 将来的な可能性（研究開発段階）

#### 🔬 複数レーダーによる局所測定の試み

**アイデア**: 複数の60GHzレーダーを異なる部位（胸部、腹部、脚部）に配置し、各部位の動きを同時測定することで、疑似的にPWVを算出する。

**課題**:
- 複数レーダー間の同期が必要（μs単位の時刻同期）
- 各レーダーの測定エリアが重ならないように配置する必要がある
- コストが高い（レーダーモジュール1個あたり約$43）

**実現可能性**: 技術的には可能だが、コストと複雑さを考えると、圧力センサー方式の方が現実的です。

#### 🔬 心拍波形の詳細解析

**アイデア**: レーダーで測定した胸部の微小変位波形から、心拍の詳細な特徴（収縮期・拡張期の動き）を抽出し、心機能を評価する。

**課題**:
- 呼吸の高調波干渉を完全に除去する必要がある
- 心拍による変位は数百μmと非常に小さく、ノイズの影響を受けやすい
- 波形の解釈が複雑（圧力センサーの脈波形状とは異なる）

**実現可能性**: 研究段階であり、臨床応用にはさらなる検証が必要です。

---

## 4. メリットとデメリットの総括

### 4.1 メリット

1. **完全非接触測定**: センサーを装着する必要がなく、長時間モニタリングに適している
2. **プライバシー保護**: カメラと異なり、映像を記録しないため、プライバシーの懸念がない
3. **環境ノイズ耐性**: 温度、湿度、光などの環境要因に影響されない
4. **複数の情報を同時取得**: 呼吸数、心拍数、体動、人体存在を同時に測定できる
5. **異なる測定原理**: 既存センサーと相補的な情報を提供し、クロスバリデーションが可能

### 4.2 デメリット

1. **局所測定不可**: 特定の動脈や血管の脈波を個別に測定できない
2. **PWV算出不可**: 単一レーダーでは複数部位の脈波到達時間差を測定できない
3. **静止状態限定**: 体動がある場合、測定精度が大幅に低下する
4. **単一ターゲット限定**: 複数人が存在すると、正確な測定ができない
5. **距離依存**: 測定対象との距離が変動すると、精度が低下する
6. **測定範囲の制限**: 心拍数60～100 bpm、呼吸数10～35回/分の範囲外は測定不可
7. **コスト**: 約$43と、他のセンサー（マイク$5、圧力センサー$10、光学式$15）より高価

---

## 5. 推奨される統合アプローチ

### 5.1 推奨構成: 60GHzレーダーを補助センサーとして追加

本プロジェクトの主目的である**血管評価（PWV測定）**には、**圧力センサー方式が最適**です。60GHzレーダーは、以下の役割で補助的に使用することを推奨します。

**構成例**:

```
【主要センサー】
- 圧力センサー × 5個（胸部、腹部、腕、脚）
  → PWV算出、血管硬化度評価

- マイク × 1個（胸部）
  → 心音検出、PEP算出

- 光学式PPG × 1個（指先）
  → SpO2測定、脈拍検出

【補助センサー】
- 60GHzレーダー × 1個（天井設置）
  → 非接触心拍・呼吸モニタリング
  → 体動検出とノイズ除去
  → 人体存在検知
```

### 5.2 データ統合の戦略

**レベル1: クロスバリデーション**
- レーダーの心拍数と圧力センサーの心拍数を比較し、測定エラーを検出
- 不一致が大きい場合、ユーザーに再測定を促す

**レベル2: ノイズ除去**
- レーダーで体動を検出した場合、その期間の光学式PPGデータを無効化
- 圧力センサーのベースライン補正にレーダーの体動情報を利用

**レベル3: コンテキスト情報の活用**
- レーダーの人体存在検知により、自動的に測定を開始/停止
- 静止状態を検出し、詳細測定（PWV算出）のタイミングを最適化

### 5.3 実装の優先順位

**Phase 1（現在）**: 圧力センサー、マイク、光学式PPGによる基本システムの構築
- PWV測定とバイタルサイン取得の実証

**Phase 2（中期）**: 60GHzレーダーの追加
- 非接触モニタリング機能の実装
- クロスバリデーションアルゴリズムの開発

**Phase 3（長期）**: 高度なデータ統合
- 機械学習による複数センサーのデータ融合
- 体動補正アルゴリズムの最適化

---

## 6. 結論

60GHzミリ波レーダー（MR60BHA1）は、**非接触で心拍数と呼吸数を測定できる**優れたセンサーですが、本プロジェクトの主目的である**血管評価（PWV測定）には直接利用できません**。その理由は、局所的な脈波測定ができないこと、複数部位の同期測定が困難なことにあります。

しかし、60GHzレーダーは**補助センサーとして非常に有用**です。異なる測定原理による心拍数のクロスバリデーション、体動検出によるノイズ除去、非接触モニタリングによる利便性向上など、既存センサーを補完する役割を果たすことができます。

**推奨事項**:
1. **Phase 1では60GHzレーダーを導入せず**、圧力センサー、マイク、光学式PPGによる基本システムの構築に集中する
2. **Phase 2以降**、補助センサーとして60GHzレーダーを追加し、非接触モニタリング機能を実装する
3. 複数レーダーによる局所測定は、コストと複雑さを考慮すると、現時点では推奨しない

60GHzレーダーは「あれば便利」だが「なくても問題ない」センサーです。予算と開発リソースに余裕がある場合に、Phase 2以降で検討することを推奨します。

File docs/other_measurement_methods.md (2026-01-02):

# その他の血流測定方法

## 序論

本プロジェクトで採用しているマイク、圧力センサー、光学式（PPG）以外にも、血流を測定するための多様な技術が存在します。本ドキュメントでは、それらの代替手法の原理、特徴、利点、および応用について概説します。

## 1. 超音波ドップラー法

超音波ドップラー法は、超音波のドップラー効果を利用して血流の速度と方向を測定する非侵襲的な手法です。医療現場で広く用いられています。

### 原理
- 超音波プローブから体内に超音波を送信し、血中の赤血球で反射した超音波を受信します。
- 赤血球がプローブに近づいている場合、反射波の周波数は高くなり、遠ざかっている場合は低くなります。
- この周波数の変化（ドップラーシフト）から血流速度を計算します。

### 種類
- **連続波ドップラー**: 送信と受信を同時に行い、特定の領域の最大血流速度を測定します。
- **パルス波ドップラー**: 短い超音波パルスを送信し、特定の深さの血流速度を測定します。
- **カラードップラー**: 血流の速度と方向を色で表示し、血流の状態を視覚的に把握できます。

### 利点
- 非侵襲的で安全
- リアルタイムでの測定が可能
- 血流の方向と速度を同時に測定可能

### 応用
- 血管の狭窄や閉塞の診断
- 心臓弁膜症の評価
- 胎児の血流測定

## 2. バイオインピーダンス法（BI）

バイオインピーダンス法は、体に微弱な電流を流し、その電気抵抗（インピーダンス）の変化から血流を測定する手法です。ウェアラブルデバイスへの応用が期待されています。

### 原理
- 血液は体組織の中で最も導電性が高いため、心拍による血流量の変化はインピーダンスの変化として現れます。
- このインピーダンスの変化を測定することで、脈波を検出し、血圧や心拍出量を推定します。

### 利点
- 非侵襲的で低消費電力
- デバイスの小型化が可能
- 連続的なモニタリングに適している

### 応用
- ウェアラブル血圧計
- 心拍出量モニター
- 体組成計

## 3. レーザードップラー法

レーザードップラー法は、レーザー光のドップラー効果を利用して、皮膚表面の微小循環（毛細血管の血流）を測定する手法です。

### 原理
- 皮膚にレーザー光を照射し、血中の赤血球で散乱した光を検出します。
- 散乱光の周波数変化から、赤血球の速度と量を反映した血流量を測定します。

### 利点
- 非侵襲的
- 微小循環の評価が可能
- 連続的な測定が可能

### 応用
- 皮膚血流の評価
- 血管内皮機能の評価
- 薬物の効果判定

## 4. MRI（磁気共鳴画像法）

MRIは、強力な磁場と電波を利用して体内の詳細な画像を得る技術ですが、血流測定にも応用されています。

### 種類
- **Phase-Contrast MRI (PC-MRI)**: 血流の速度と方向を定量的に測定し、3Dで可視化できます。
- **Arterial Spin Labeling (ASL)**: 血液中の水分子を磁気的に標識し、組織への血流を測定します。

### 利点
- 非侵襲的で放射線被ばくがない
- 全身の血管を詳細に描出可能
- 血流量の定量的な評価が可能

### 応用
- 脳血流測定
- 心臓の血流評価
- 血管奇形の診断

## 5. その他の手法

- **熱希釈法**: 冷たい液体を静脈に注入し、下流の動脈での温度変化から心拍出量を測定する侵襲的な手法です。
- **PET（陽電子放出断層撮影）**: 放射性トレーサーを用いて、組織の血流や代謝を定量的に測定します。

## まとめ

| 手法 | 原理 | 利点 | 欠点 | 主な応用 |
|---|---|---|---|---|
| 超音波ドップラー | ドップラー効果 | 非侵襲、リアルタイム | 測定者の技量に依存 | 血管診断、心臓評価 |
| バイオインピーダンス | 電気抵抗変化 | 低消費電力、小型化 | 動きに弱い | ウェアラブルデバイス |
| レーザードップラー | ドップラー効果 | 微小循環評価 | 測定深度が浅い | 皮膚血流評価 |
| MRI | 核磁気共鳴 | 高解像度、定量的 | 高コスト、長時間 | 脳・心臓血流評価 |
| 熱希釈法 | 温度変化 | 高精度 | 侵襲的 | 心拍出量測定 |
| PET | 放射性トレーサー | 定量的、代謝評価 | 放射線被ばく、高コスト | がん診断、心筋評価 |

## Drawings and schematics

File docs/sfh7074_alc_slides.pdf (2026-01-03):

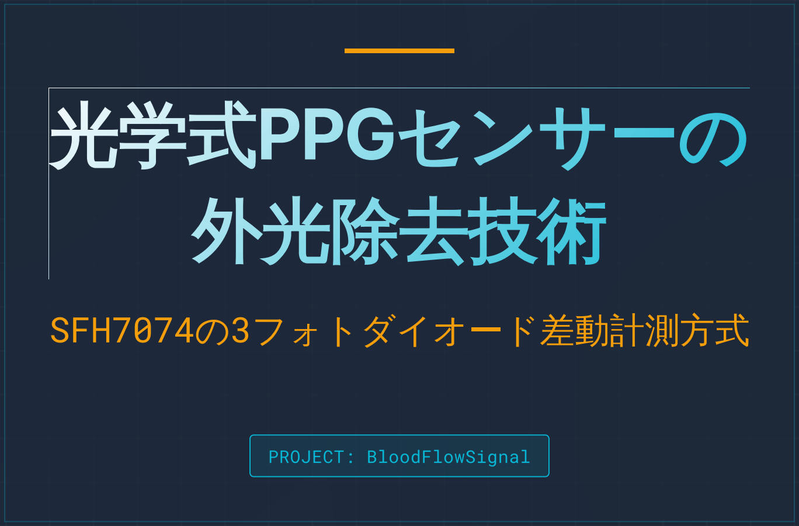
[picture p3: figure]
SFH7074の3フォトダイオード差動計測方式; PROJECT: BloodFlowSignal

外光ノイズの問題 | 02 / 10

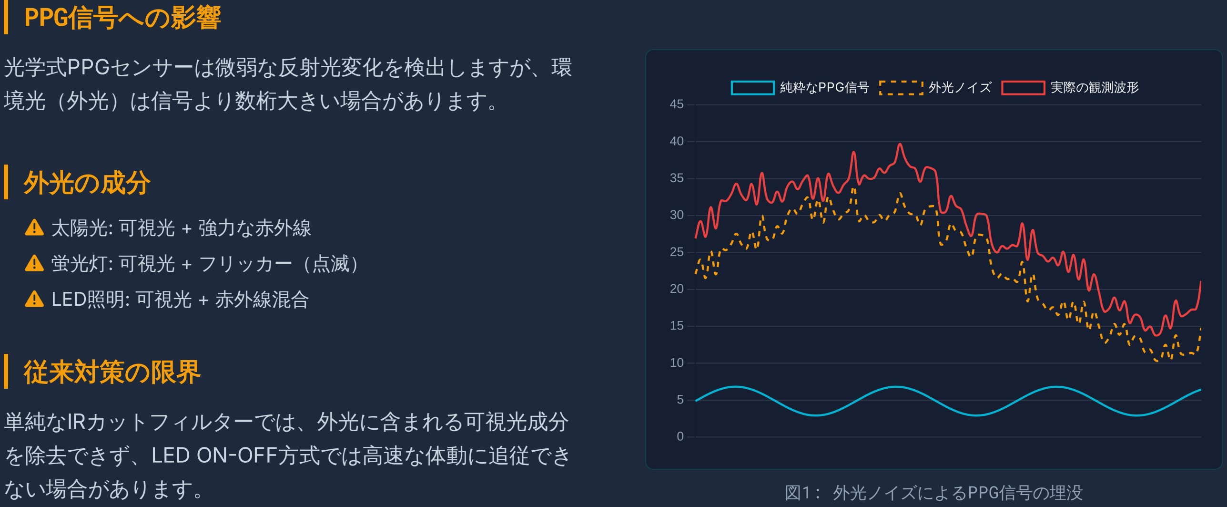
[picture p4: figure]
PPG信号への影響; 光学式PPGセンサーは微弱な反射光変化を検出しますが、環 境光（外光）は信号より数桁大きい場合があります。; 外光の成分; 従来対策の限界; 単純なIRカットフィルターでは、外光に含まれる可視光成分 を除去できず、LED ONOFF方式では高速な体動に追従でき; ない場合があります。; 図1: 外光ノイズによるPPG信号の埋没; 太陽光: 可視光 + 強力な赤外線; 蛍光灯: 可視光 + フリッカー（点滅）; LED照明: 可視光 + 赤外線混合

SFH7074の構成 | 03 / 10

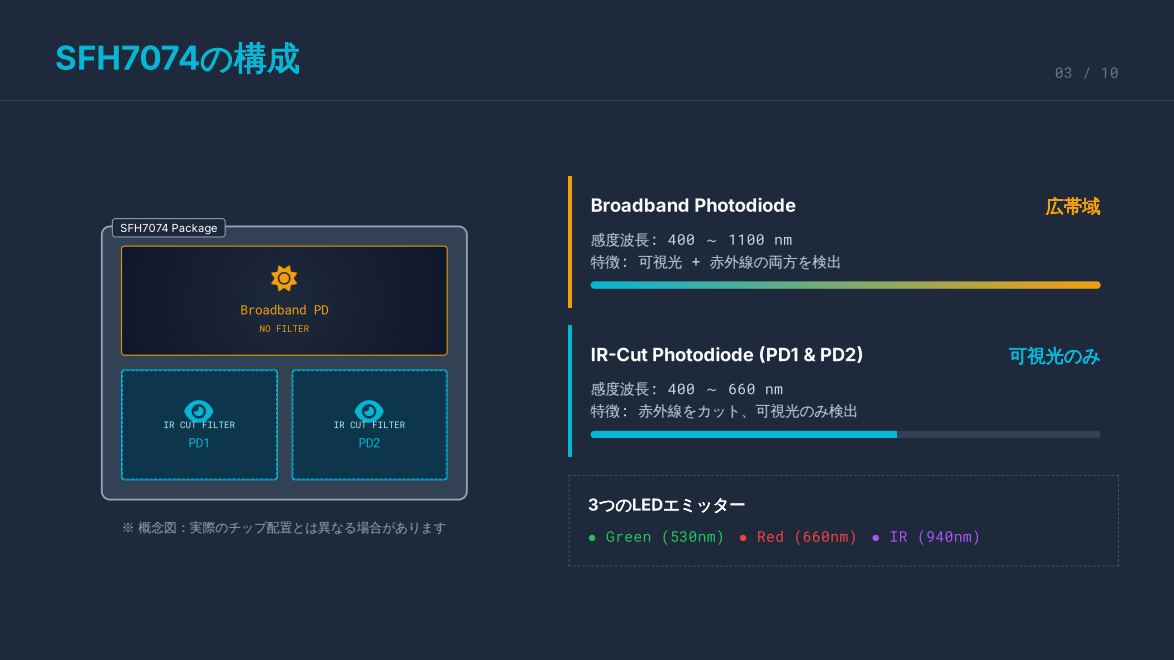
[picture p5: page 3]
※ 概念図：実際のチップ配置とは異なる場合があります; Broadband Photodiode; 広帯域; IRCut Photodiode PD1 & PD2; 可視光のみ; 3つのLEDエミッター; Broadband PD; NO FILTER; IR CUT FILTER; SFH7074 Package

感度波長: 400 ～ 1100 nm
特徴: 可視光 + 赤外線の両方を検出

感度波長: 400 ～ 660 nm
特徴: 赤外線をカット、可視光のみ検出

IR CUT FILTER

● Green (530nm) ● Red (660nm) ● IR (940nm)

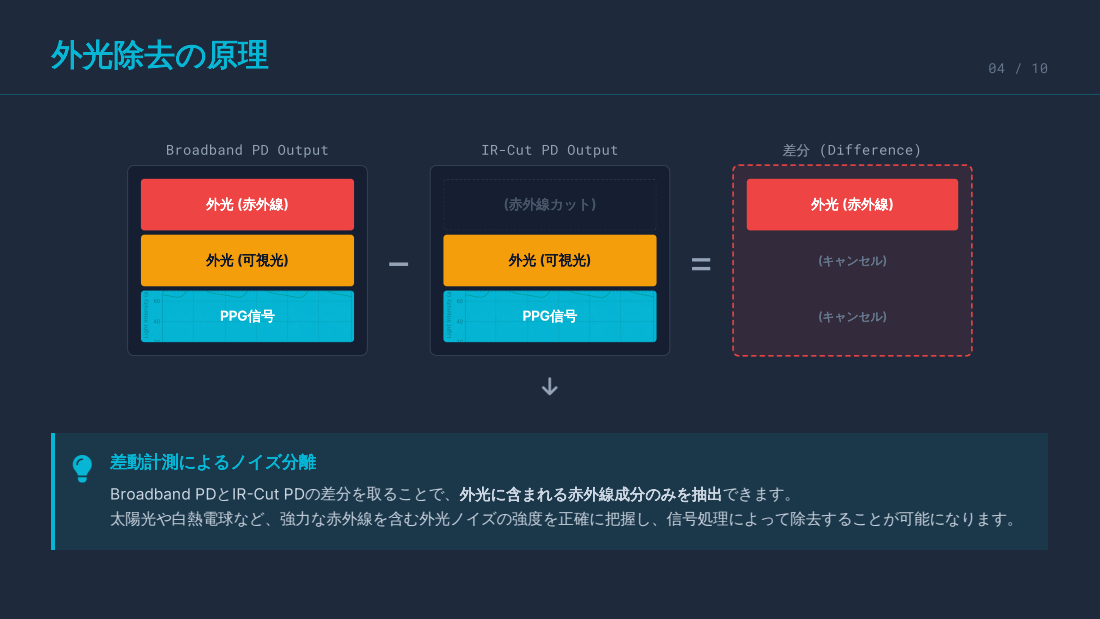
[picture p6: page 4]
外光除去の原理; 外光 (赤外線); 外光 (可視光); (赤外線カット); 差分 (Difference); (キャンセル); PPG信号

Broadband PD Output

IR-Cut PD Output

差動計測によるノイズ分離
Broadband PDとIRCut PDの差分を取ることで、外光に含まれる赤外線成分のみを抽出できます。
太陽光や白熱電球など、強力な赤外線を含む外光ノイズの強度を正確に把握し、信号処理によって除去することが可能になります。

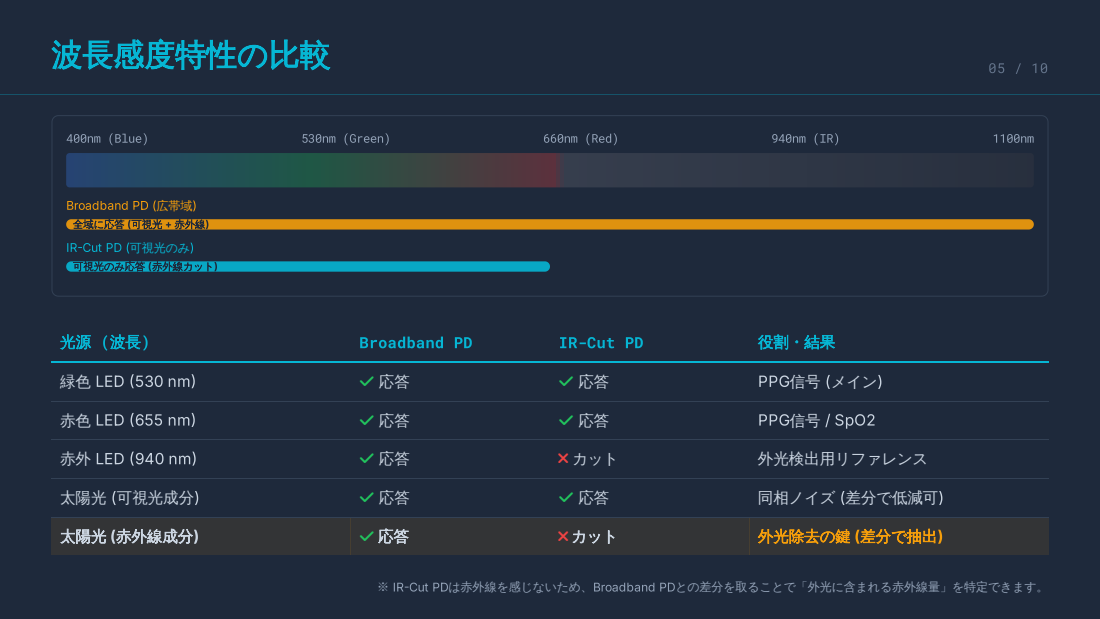
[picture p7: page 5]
波長感度特性の比較; 400nm (Blue); 530nm (Green); 660nm (Red); Broadband PD; IR-Cut PD; 緑色 LED 530 nm; PPG信号 (メイン); 赤色 LED 655 nm; PPG信号 / SpO2; 赤外 LED 940 nm; カット; 外光検出用リファレンス; 太陽光 (可視光成分); 同相ノイズ (差分で低減可); 太陽光 (赤外線成分); 外光除去の鍵 (差分で抽出); 可視光のみ応答 (赤外線カット)

Broadband PD (広帯域)

全域に応答 (可視光 + 赤外線)
IRCut PD (可視光のみ)

※ IRCut PDは赤外線を感じないため、Broadband PDとの差分を取ることで「外光に含まれる赤外線量」を特定できます。

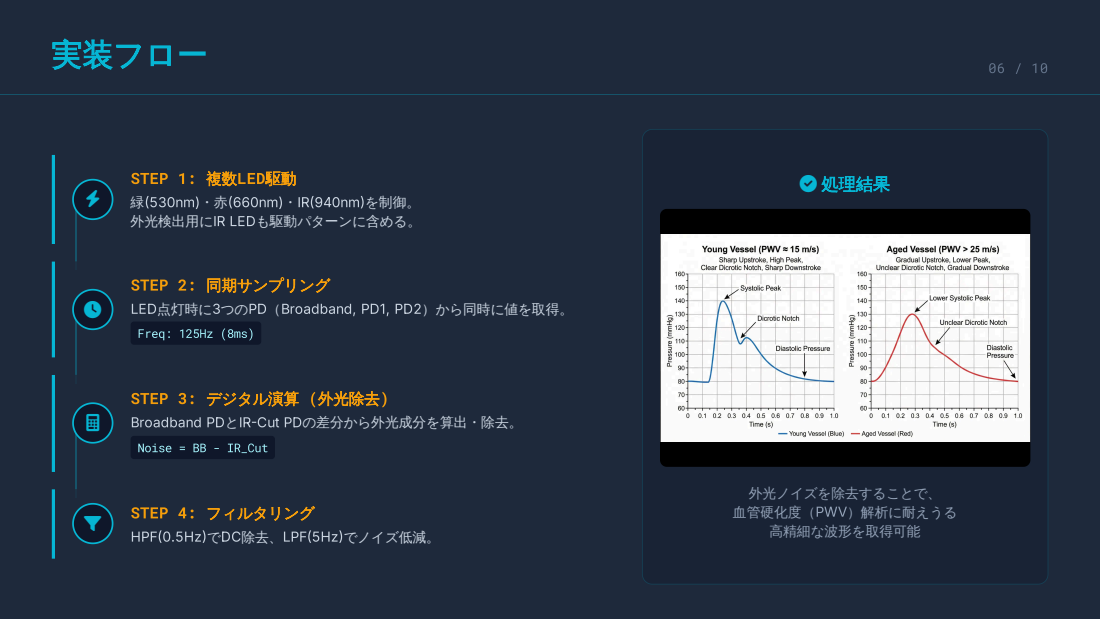
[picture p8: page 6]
実装フロー; 処理結果; STEP 1: 複数LED駆動 緑530nm)・赤660nm)・IR940nmを制御。 外光検出用にIR LEDも駆動パターンに含める。; STEP 2: 同期サンプリング; LED点灯時に3つのPD（Broadband, PD1, PD2）から同時に値を取得。; Freq: 125Hz (8ms); Noise = BB - IR_Cut; STEP 4: フィルタリング

STEP 3: デジタル演算 (外光除去)
Broadband PDとIRCut PDの差分から外光成分を算出・除去。

外光ノイズを除去することで、
血管硬化度（PWV）解析に耐えうる
高精細な波形を取得可能

HPF0.5HzでDC除去、LPF5Hzでノイズ低減。

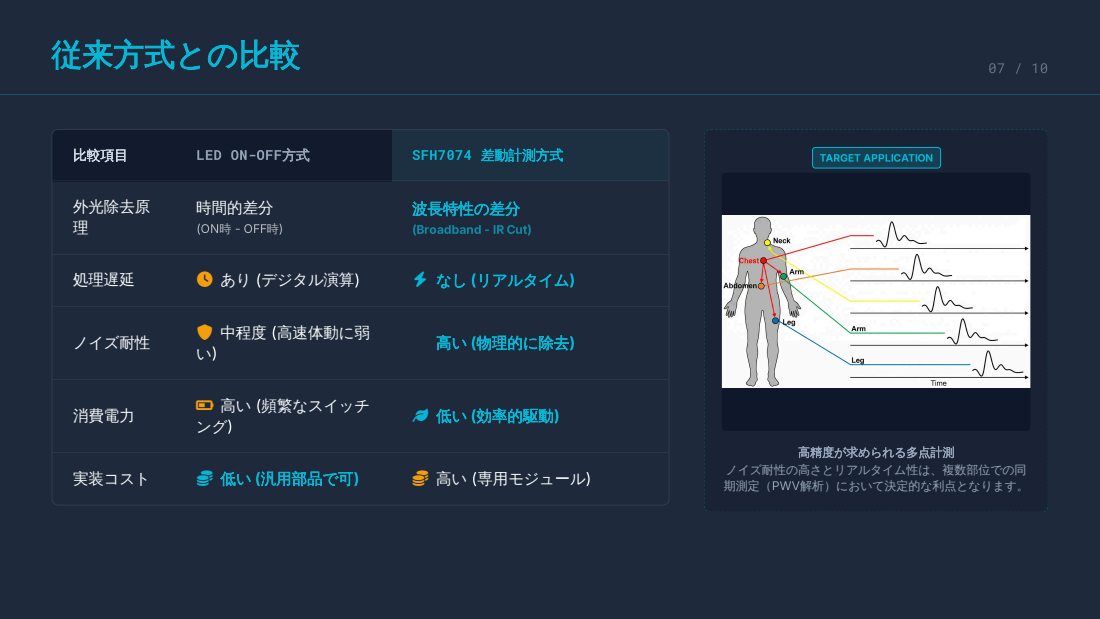
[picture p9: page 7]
従来方式との比較; 比較項目; LED ON-OFF方式; SFH7074 差動計測方式; 外光除去原 理; 時間的差分; 波長特性の差分; 処理遅延; あり (デジタル演算); なし (リアルタイム); ノイズ耐性; 中程度 (高速体動に弱; 高い (物理的に除去); 消費電力; 高い (頻繁なスイッチ; 低い (効率的駆動); 実装コスト; 低い (汎用部品で可); 高い (専用モジュール); TARGET APPLICATION; 高精度が求められる多点計測; (ON時 - OFF時); (Broadband - IR Cut)

ノイズ耐性の高さとリアルタイム性は、複数部位での同
期測定（PWV解析）において決定的な利点となります。

BloodFlowSignalプロジェクトへの適用 | 08 / 10

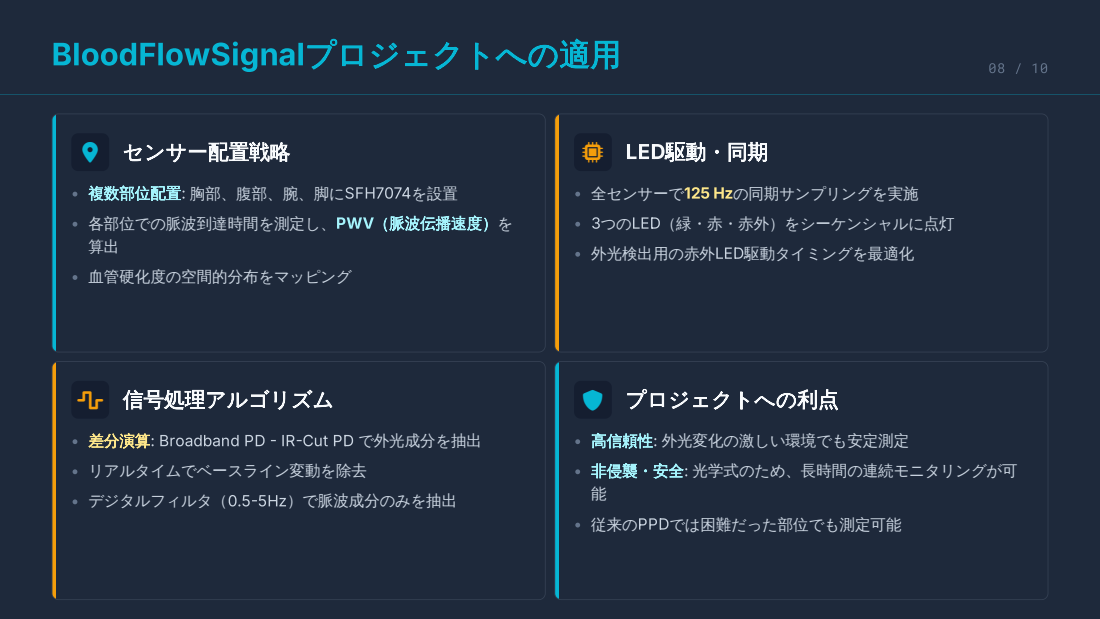
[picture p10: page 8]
センサー配置戦略; LED駆動・同期; • 全センサーで125 Hzの同期サンプリングを実施; • 3つのLED（緑・赤・赤外）をシーケンシャルに点灯; • 外光検出用の赤外LED駆動タイミングを最適化; 信号処理アルゴリズム; プロジェクトへの利点; • 高信頼性: 外光変化の激しい環境でも安定測定; 非侵襲・安全: 光学式のため、長時間の連続モニタリングが可 能; • 従来のPPDでは困難だった部位でも測定可能

• 複数部位配置: 胸部、腹部、腕、脚にSFH7074を設置
各部位での脈波到達時間を測定し、PWV（脈波伝播速度）を
• 血管硬化度の空間的分布をマッピング

• 差分演算: Broadband PD  IRCut PD で外光成分を抽出
• リアルタイムでベースライン変動を除去
• デジタルフィルタ（0.55Hz）で脈波成分のみを抽出

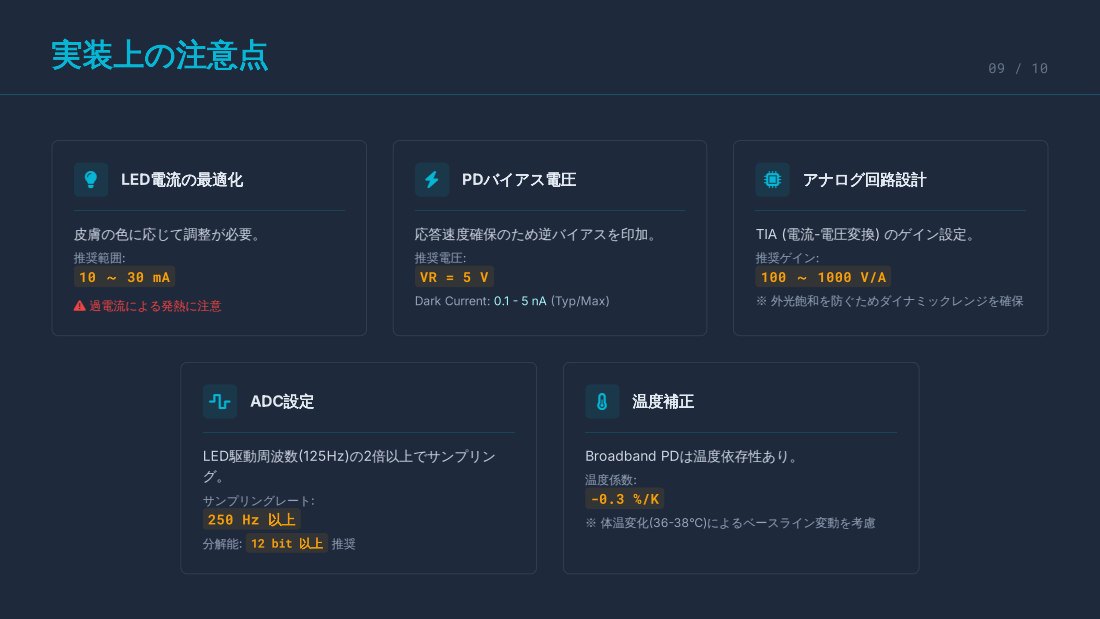
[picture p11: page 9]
実装上の注意点; LED電流の最適化; 皮膚の色に応じて調整が必要。; 推奨範囲:; 過電流による発熱に注意; PDバイアス電圧; 応答速度確保のため逆バイアスを印加。; 推奨電圧:; アナログ回路設計; 100 ～ 1000 V/A ※ 外光飽和を防ぐためダイナミックレンジを確保; ADC設定; 温度補正; Broadband PDは温度依存性あり。; 温度係数:; -0.3 %/K ※ 体温変化3638°C)によるベースライン変動を考慮

TIA (電流-電圧変換) のゲイン設定。
推奨ゲイン:

Dark Current: 0.1  5 nA Typ/Max)

LED駆動周波数125Hz)の2倍以上でサンプリン
サンプリングレート:
分解能: 12 bit 以上 推奨

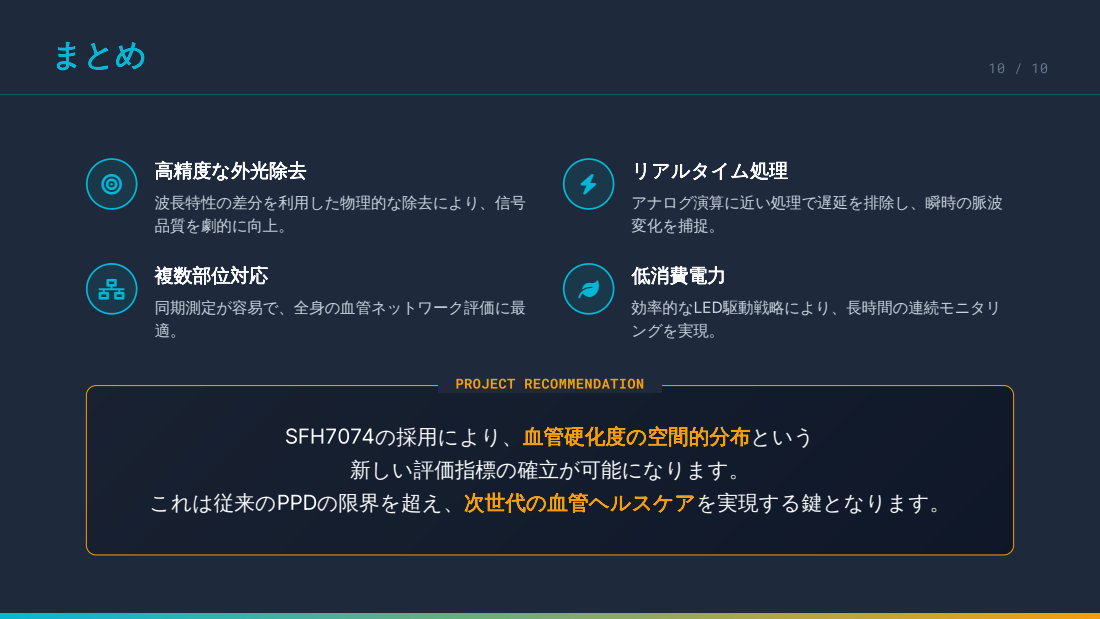
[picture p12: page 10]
まとめ; 高精度な外光除去; 波長特性の差分を利用した物理的な除去により、信号 品質を劇的に向上。; リアルタイム処理; アナログ演算に近い処理で遅延を排除し、瞬時の脈波 変化を捕捉。; 複数部位対応; 同期測定が容易で、全身の血管ネットワーク評価に最 適。; 低消費電力; 効率的なLED駆動戦略により、長時間の連続モニタリ ングを実現。; SFH7074の採用により、血管硬化度の空間的分布という 新しい評価指標の確立が可能になります。 これは従来のPPDの限界を超え、次世代の血管ヘルスケアを実現する鍵となります。; PROJECT RECOMMENDATION

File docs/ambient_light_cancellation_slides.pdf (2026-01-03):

# 光学式PPGセンサーの

# 外光除去技術

# 2個電荷リザーバ方式の原理と実装

# PPG測定における3つの主要な干渉成分

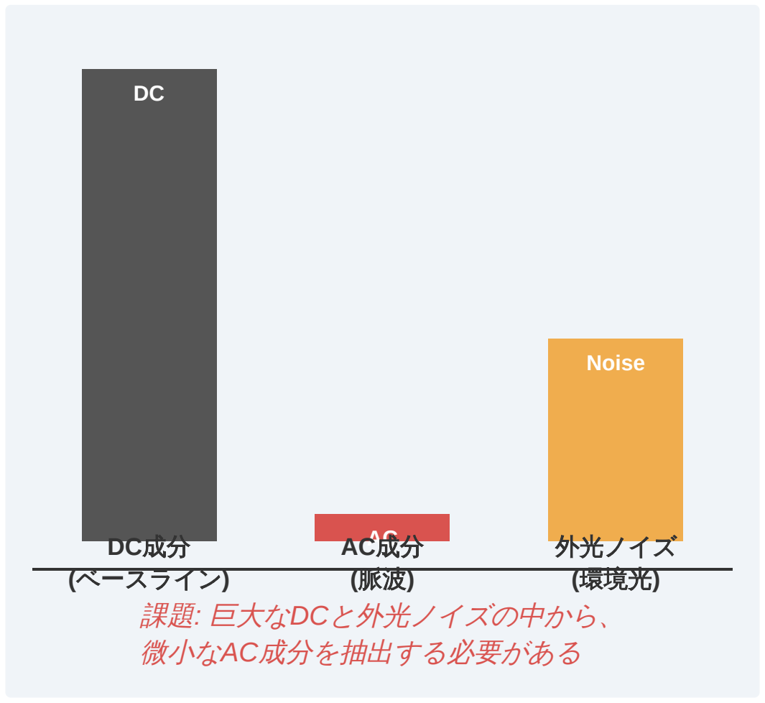
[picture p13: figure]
課題: 巨大なDCと外光ノイズの中から、 微小なAC成分を抽出する必要がある; DC成分 (ベースライン); AC AC成分 (脈波); Noise; 外光ノイズ (環境光)

## 1. DC成分（直流オフセット）

組織からの反射光ベースライン。脈波信号より100倍以上 大きい。

## 2. AC成分（脈波信号）

心拍による血液量変化。測定したい微弱な信号。

## 3. 外光ノイズ

環境光（蛍光灯、太陽光）。AC成分を大きく汚染する。

# 従来のLED ON-OFF方式による外光除去

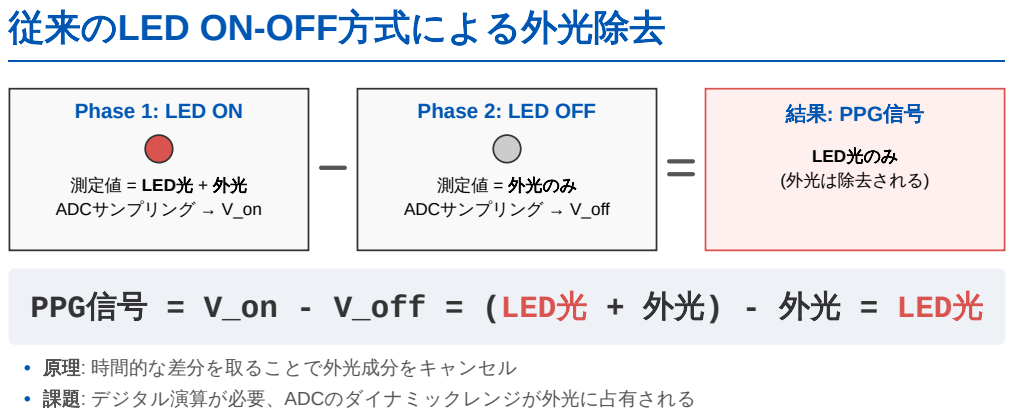
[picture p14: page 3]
測定値 = 外光のみ ADCサンプリング → V_off; 結果: PPG信号; LED光のみ (外光は除去される)

Phase 1: LED ON

Phase 2: LED OFF

測定値 = LED光 + 外光
ADCサンプリング → V_on

PPG信号 = V_on - V_off = (LED光 + 外光) - 外光 = LED光

• 原理: 時間的な差分を取ることで外光成分をキャンセル
• 課題: デジタル演算が必要、ADCのダイナミックレンジが外光に占有される

# アナログ領域での外光除去 - 2個電荷リザーバ方式

PD/TIA; ADC; CPU 差分; 外光を含んだままADC変換 (ダイナミックレンジを浪費); 今回: 2個電荷リザーバ方式; 再分配; 外光を除去してからADC変換 (微弱信号を高精度に測定); 主な利点 低消費電力 — デジタル演算不要 (26.4 μW程度); 高ダイナミックレンジ — ADCレンジ を信号に集中できる; リアルタイム処理 — 遅延がほぼな い、瞬時に除去完了

原理は同じ（時間的差分）だが、差分を取る場所が異なる

従来: LED ON-OFF方式

# 2個電荷リザーバ方式の回路構成

フォトダイオード。受光した光量に応じた電流を生成す; TIA; トランスインピーダンスアンプ。微弱な電流を電圧信号に; 変換・増幅する。; S1/S2 サンプリングスイッチ。LEDの点灯タイミングに合わせて 信号を振り分ける。; 再分配スイッチ（図中省略）。CrとCaを接続して差分を取; Output 外光成分が除去された純粋なPPG信号が出力される。; フォト ダイオード; LED ON用; LED OFF用; リザーバ1; リザーバ2; Output; 差分出力 (S3で再分配)

Cr/Ca 電荷リザーバ（コンデンサ）。信号電荷を一時的に保存す

# Phase 1: LED ON時に信号をCrに保存

スイッチ状態; S2: OFF (切断); S3: OFF (切断); 信号とノイズの両方が リザーバCrに蓄積される; Cr (保存中)

入力信号
LED: 点灯 (ON)
入力 = LED光 + 外光

Qr = Cr × (VLED + VAL)

# Phase 2: LED OFF時に信号をCaに保存

スイッチ状態; S1: 切断 (OFF); S3: 切断 (OFF); 測定内容; (V : 外光電圧); LED (OFF); S1 (OFF) Cr; Charge Stored

LED: 消灯
入力: 外光のみ (ノイズ)
保存先: 電荷リザーバ Ca

保存される電荷
Qa = Ca × VAL

# Phase 3: CrとCaを逆極性で接続し電荷再分配

スイッチ状態; S1: OFF (切断); S2: OFF (切断); CrとCaが逆向きに接続され、 電荷の差分が取られる; Step 2: 保存された電荷を代入; Step 3: 外光成分の相殺; Vout ∝ VLED +; VAL - VAL; 外光ノイズが完全に除去され、 純粋なPPG信号のみが残る

Step 1: 電荷再分配の基本式
Vout = (Qr - Qa) / (Cr + Ca)

Vout ∝ (VLED + VAL) - VAL

逆極性接続 (Reverse Polarity)

結果: Vout = VLED / 2

# 完全なタイミング制御フロー

Phase; LED; S3 (Out); Phase 2: サンプリング (OFF) LED消灯。 S2を閉じて、外光のみをCaに充電。 (約4ms); Phase 3: 電荷再分配・出力 S1, S2を開放。 S3を閉じてCrとCaを接続。 差分電圧を出力。; ※ 全体のサイクル周波数: 約125Hz (周期8ms); Phase 1; Phase 2; Phase 3

Phase 1: サンプリング (ON)
LED点灯。
S1を閉じて、信号+外光をCrに充電。

# なぜ外光が除去されるのか？

= C と仮定); 逆極性接続により完全に相殺される

Step 1 Phase 1: Crに信号とノイズを保存
Qr = Cr × (VLED + VAL)

Step 2 Phase 2: Caにノイズのみを保存
Qa = Ca × VAL

Step 3 逆極性接続による差分計算 (Cr
Vout = (Qr - Qa) / 2C

Step 4 展開と相殺
Vout = [C(VLED + VAL) -
CVAL] / 2C = VLED / 2

結論: 外光成分 (VAL) は両方のリザーバに等しく保存されるため、

# 2つの外光除去方式の比較

比較項目 | LED ON-OFF方式 (デジタル) | 2個電荷リザーバ方式 (アナログ)
差分の場所 | ADC変換後 (CPU演算) | ADC変換前 (回路動作)
ダイナミックレン ジ | 外光がADC範囲を消費 | 信号のみにADC範囲を使用
消費電力 | 中～高 (CPU負荷あり) | 極めて低い (26.4 μW)
リアルタイム性 | 演算遅延あり | 遅延ほぼなし (瞬時)
回路の複雑さ | シンプル (ソフト処理) | 中程度 (スイッチ・容量が必要)
精度要因 | ADC分解能に依存 | 容量マッチング (Cr=Ca) に依存
実装コスト | 低い (既存マイコンで可) | 専用ICまたは回路設計が必要

結論: 性能重視ならアナログ方式、 実装容易性重視ならデジタル方式

# 実装上の注意点

2個電荷リザーバ方式を成功させるための重要な技術要件; 電荷リザーバのマッチング (最重要); CrとCaの容量を事実上一致させる必要があります。許容差は ±0.1% 程度を目安にしてください。; スイッチのリーク電流; 保存電荷の漏れは測定誤差を招きます。リークの小さいスイ ッチを選定してください。; タイミング精度; 切替のデッドタイムを確保し、スイッチの同時ONを防止しま す。; ノイズ対策とシールド; 微小電荷は外来ノイズに敏感です。グラウンドガードや金属シールドを推奨します。; ※ アナログ方式は部品選定と基板設計で高い精度が求められます。

温度安定性
温度係数の小さいコンデンサ（C0G/NP0 等）を選び、容量変
動を抑えます。

# BloodFlowSignalプロジェクトでの外光除去の実装

方法1: デジタル差分; 方法2: アナログ差分; 推奨・初期実装; 高性能・将来検討

現状のハードウェア制約
使用予定の秋月電子モジュール（LED + PD）は、外光除去回路を内蔵していません。 そのため、外部で外光除
去機能を実装する必要があります。

実装:Seeeduino XIAOで制御
処理:LED ON/OFF時にADC計測し、ソフトウェアで減算
利点:追加回路不要、実装が容易
欠点:CPU負荷増、消費電力やや高

実装:外部スイッチ回路を追加
処理:電荷再分配で物理的に除去
利点:低消費電力、高ダイナミックレンジ
欠点:回路設計・製作が複雑

結論: まずは「方法1 (デジタル差分)」で開発を進め、S/N比が不足する場合や省電力化が必要な段階で「方
法2」を検討します。

# まとめ

技術的要点; アナログ領域での除去により、微弱なPPG信号を 高精度に抽出可能。; 逆極性接続を利用した電荷再分配が、外光キャン セルの核心原理。; デジタル方式と比較して、低消費電力かつ高ダイ ナミックレンジを実現。; 今後のアクションプラン; 段階的なアプローチで、信頼性の高い血流モニタリングシステムを構築しましょう

まずはデジタル差分方式 (LED ON-OFF) を
Seeeduino XIAOで実装する。
推奨周期 8ms (125Hz) でサンプリングを行い、外
光ノイズの影響を評価する。
S/N比が不十分な場合のみ、アナログ回路（2個電
荷リザーバ方式）の導入を検討する。

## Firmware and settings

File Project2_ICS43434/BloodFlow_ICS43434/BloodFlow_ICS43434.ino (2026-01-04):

/*
 * Project2: M5AtomS3とICS-43434マイクによる血流計測
 * 
 * このスケッチは、M5AtomS3とICS-43434 MEMSマイクを使用して
 * 血流音を計測し、シリアルプロッター経由でリアルタイムに可視化します。
 * 
 * ハードウェア接続:
 * - M5AtomS3 G5  -> ICS-43434 SCK
 * - M5AtomS3 G6  -> ICS-43434 WS
 * - M5AtomS3 G7  -> ICS-43434 SD
 * - M5AtomS3 3V3 -> ICS-43434 VIN
 * - M5AtomS3 GND -> ICS-43434 GND
 * - M5AtomS3 GND -> ICS-43434 SEL (Left channel)
 * 
 * 使用方法:
 * 1. Arduino IDEでこのスケッチをM5AtomS3に書き込む
 * 2. ツール -> シリアルプロッターを開く
 * 3. マイクを手首や首の動脈付近に配置する
 * 4. 波形を観察する
 */

#include <M5Unified.h>
#include <driver/i2s.h>

// I2S設定
#define I2S_PORT I2S_NUM_0
#define SAMPLE_RATE 16000           // サンプリングレート 16kHz
#define SAMPLE_BUFFER_SIZE 256      // バッファサイズ
#define BITS_PER_SAMPLE I2S_BITS_PER_SAMPLE_32BIT

// M5AtomS3のピン設定
#define I2S_MIC_SERIAL_CLOCK GPIO_NUM_5     // SCK (ビットクロック)
#define I2S_MIC_LEFT_RIGHT_CLOCK GPIO_NUM_6 // WS (ワードセレクト)
#define I2S_MIC_SERIAL_DATA GPIO_NUM_7      // SD (データ)

// I2S設定構造体
i2s_config_t i2s_config = {
    .mode = (i2s_mode_t)(I2S_MODE_MASTER | I2S_MODE_RX),
    .sample_rate = SAMPLE_RATE,
    .bits_per_sample = BITS_PER_SAMPLE,
    .channel_format = I2S_CHANNEL_FMT_ONLY_LEFT,
    .communication_format = I2S_COMM_FORMAT_STAND_I2S,
    .intr_alloc_flags = ESP_INTR_FLAG_LEVEL1,
    .dma_buf_count = 4,
    .dma_buf_len = 1024,
    .use_apll = false,
    .tx_desc_auto_clear = false,
    .fixed_mclk = 0
};

// I2Sピン設定構造体
i2s_pin_config_t i2s_mic_pins = {
    .bck_io_num = I2S_MIC_SERIAL_CLOCK,
    .ws_io_num = I2S_MIC_LEFT_RIGHT_CLOCK,
    .data_out_num = I2S_PIN_NO_CHANGE,
    .data_in_num = I2S_MIC_SERIAL_DATA
};

// グローバル変数
int32_t raw_samples[SAMPLE_BUFFER_SIZE];
bool i2s_initialized = false;

void setup() {
    // M5Unifiedの初期化
    auto cfg = M5.config();
    M5.begin(cfg);
    
    // ディスプレイ初期化
    M5.Display.setRotation(0);
    M5.Display.setTextSize(1);
    M5.Display.fillScreen(BLACK);
    M5.Display.setCursor(0, 10);
    M5.Display.println("BloodFlow");
    M5.Display.println("Monitor");
    M5.Display.println("");
    M5.Display.println("ICS-43434");
    
    // シリアル通信の初期化
    Serial.begin(115200);
    while (!Serial) {
        delay(10);
    }
    
    delay(1000);
    
    // I2Sドライバのインストール
    esp_err_t err = i2s_driver_install(I2S_PORT, &i2s_config, 0, NULL);
    if (err != ESP_OK) {
        Serial.printf("I2S driver install error: %d\n", err);
        M5.Display.fillScreen(RED);
        M5.Display.setCursor(0, 30);
        M5.Display.println("I2S Error!");
        while (1) {
            delay(1000);
        }
    }
    
    // I2Sピンの設定
    err = i2s_set_pin(I2S_PORT, &i2s_mic_pins);
    if (err != ESP_OK) {
        Serial.printf("I2S pin set error: %d\n", err);
        M5.Display.fillScreen(RED);
        M5.Display.setCursor(0, 30);
        M5.Display.println("Pin Error!");
        while (1) {
            delay(1000);
        }
    }
    
    i2s_initialized = true;
    
    // 初期化完了メッセージ
    Serial.println("# BloodFlow Monitor - ICS-43434");
    Serial.println("# Ready to measure...");
    
    M5.Display.fillScreen(GREEN);
    M5.Display.setCursor(0, 30);
    M5.Display.println("Ready!");
    
    delay(1000);
    M5.Display.fillScreen(BLACK);
}

void loop() {
    M5.update();
    
    if (!i2s_initialized) {
        return;
    }
    
    // I2Sデバイスからデータを読み取る
    size_t bytes_read = 0;
    esp_err_t result = i2s_read(
        I2S_PORT,
        raw_samples,
        sizeof(int32_t) * SAMPLE_BUFFER_SIZE,
        &bytes_read,
        portMAX_DELAY
    );
    
    if (result != ESP_OK) {
        Serial.println("# I2S read error");
        return;
    }
    
    int samples_read = bytes_read / sizeof(int32_t);
    
    // サンプルデータをシリアルプロッターに出力
    // 32ビットデータを右シフトして適切な範囲に正規化
    for (int i = 0; i < samples_read; i++) {
        // 上位24ビットを使用（ICS-43434は24ビット出力）
        int32_t sample = raw_samples[i] >> 8;
        Serial.println(sample);
    }
    
    // ボタンが押されたら情報を表示
    if (M5.BtnA.wasPressed()) {
        M5.Display.fillScreen(BLACK);
        M5.Display.setCursor(0, 10);
        M5.Display.printf("Rate:%dHz\n", SAMPLE_RATE);
        M5.Display.printf("Buf:%d\n", SAMPLE_BUFFER_SIZE);
        M5.Display.printf("Read:%d\n", samples_read);
        delay(2000);
        M5.Display.fillScreen(BLACK);
    }
}

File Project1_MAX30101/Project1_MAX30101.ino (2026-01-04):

/*
  Project1_MAX30101: M5AtomS3による血流計測（緑LEDのみ使用）
  
  このスケッチは、M5AtomS3とSparkFun SEN-16474 (MAX30101)を使用して、
  緑色LEDの反射データを取得し、シリアル経由でPCに出力します。
  緑LEDは皮膚表面の血流変化検出に最も感度が高く、心拍計測に適しています。
  
  接続:
  - M5AtomS3 G38 (SDA) -> MAX30101 SDA
  - M5AtomS3 G39 (SCL) -> MAX30101 SCL
  - M5AtomS3 3.3V -> MAX30101 3.3V (注: 緑LEDには5V推奨だが3.3Vでも動作)
  - M5AtomS3 GND -> MAX30101 GND
  
  必要なライブラリ:
  - M5Unified
  - SparkFun MAX3010x Pulse and Proximity Sensor Library
  
  使用方法:
  1. このコードをM5AtomS3に書き込む
  2. Arduino IDEのシリアルプロッタを開く (ツール > シリアルプロッタ)
  3. ボーレートを115200に設定
  4. センサーに指を置いてデータを確認
  
  外光ノイズ対策:
  - MAX30101内蔵のAmbient Light Cancellation (ALC)機能が自動的に動作
  - ALCはTrack/Holdサーキットで外光を自動キャンセル
  
  注意: このコードは教育・デモ目的であり、医療診断には使用できません。
*/

#include <M5Unified.h>
#include <Wire.h>
#include "MAX30105.h"

MAX30105 particleSensor;

// I2Cピン定義 (M5AtomS3)
#define SDA_PIN 38
#define SCL_PIN 39

void setup() {
  // M5AtomS3初期化
  auto cfg = M5.config();
  M5.begin(cfg);
  
  // ディスプレイに初期化メッセージを表示
  M5.Display.setTextSize(1);
  M5.Display.setTextColor(WHITE);
  M5.Display.setCursor(10, 10);
  M5.Display.println("MAX30101");
  M5.Display.setCursor(10, 30);
  M5.Display.println("Init...");
  
  // シリアル通信開始
  Serial.begin(115200);
  Serial.println("MAX30101 Blood Flow Measurement (Green LED Only)");
  Serial.println("================================================");
  
  // I2C初期化 (M5AtomS3のI2Cピンを指定)
  Wire.begin(SDA_PIN, SCL_PIN);
  
  // MAX30101センサー初期化
  if (!particleSensor.begin(Wire, I2C_SPEED_FAST)) {
    Serial.println("ERROR: MAX30101 was not found. Please check wiring/power.");
    M5.Display.fillScreen(RED);
    M5.Display.setCursor(10, 50);
    M5.Display.println("ERROR!");
    while (1);
  }
  
  Serial.println("MAX30101 detected!");
  
  // センサー設定（緑LEDのみ使用）
  // パラメータ: ledBrightness, sampleAverage, ledMode, sampleRate, pulseWidth, adcRange
  byte ledBrightness = 0x3F;  // LED輝度 (0x00 - 0xFF) 緑LEDは高めに設定
  byte sampleAverage = 4;     // サンプル平均 (1, 2, 4, 8, 16, 32)
  byte ledMode = 3;           // LEDモード: 3 = 全LED使用可能（個別制御）
  int sampleRate = 100;       // サンプルレート (50, 100, 200, 400, 800, 1000, 1600, 3200)
  int pulseWidth = 411;       // パルス幅 (69, 118, 215, 411) マイクロ秒
  int adcRange = 4096;        // ADC範囲 (2048, 4096, 8192, 16384)
  
  particleSensor.setup(ledBrightness, sampleAverage, ledMode, sampleRate, pulseWidth, adcRange);
  
  // 緑LEDのみを有効化（赤とIRを消灯）
  // これにより外光ノイズの影響を最小化し、緑LEDの高感度特性を活用
  particleSensor.setPulseAmplitudeRed(0);      // 赤LED OFF
  particleSensor.setPulseAmplitudeIR(0);       // IR LED OFF
  particleSensor.setPulseAmplitudeGreen(0x3F); // 緑LED ON (輝度: 0x3F)
  
  // Ambient Light Cancellation (ALC)は自動的に有効
  // ALCはMAX30101内部のTrack/Holdサーキットで外光を自動キャンセル
  
  Serial.println("Setup complete!");
  Serial.println("Configuration:");
  Serial.println("- LED Mode: Green only");
  Serial.println("- Sample Rate: 100 Hz");
  Serial.println("- Pulse Width: 411 us");
  Serial.println("- ADC Range: 4096");
  Serial.println("- Ambient Light Cancellation: Enabled (automatic)");
  Serial.println("");
  Serial.println("Place your finger on the sensor.");
  Serial.println("Green");  // シリアルプロッタ用のヘッダー
  
  // 初期化完了
  M5.Display.fillScreen(GREEN);
  M5.Display.setCursor(10, 50);
  M5.Display.println("Ready!");
  M5.Display.setCursor(10, 70);
  M5.Display.setTextSize(1);
  M5.Display.println("Green LED");
  
  delay(1000);
  M5.Display.fillScreen(BLACK);
}

void loop() {
  M5.update();  // M5AtomS3のボタン状態などを更新
  
  // センサーから緑色LEDのデータを取得
  long green = particleSensor.getGreen();
  
  // シリアルプロッタ用に出力
  Serial.println(green);
  
  // ディスプレイに簡易表示
  static unsigned long lastDisplayUpdate = 0;
  if (millis() - lastDisplayUpdate > 500) {  // 500msごとに更新
    lastDisplayUpdate = millis();
    
    M5.Display.fillScreen(BLACK);
    M5.Display.setTextSize(1);
    M5.Display.setCursor(5, 10);
    M5.Display.setTextColor(GREEN);
    M5.Display.println("Blood Flow");
    M5.Display.setTextColor(WHITE);
    
    M5.Display.setCursor(5, 30);
    M5.Display.print("Green: ");
    M5.Display.println(green);
    
    // 信号強度インジケーター
    // 緑LEDは赤やIRよりも反射が強いため、閾値を調整
    if (green > 80000) {
      M5.Display.setCursor(5, 50);
      M5.Display.setTextColor(GREEN);
      M5.Display.println("Excellent");
    } else if (green > 50000) {
      M5.Display.setCursor(5, 50);
      M5.Display.setTextColor(GREEN);
      M5.Display.println("Good Signal");
    } else if (green > 10000) {
      M5.Display.setCursor(5, 50);
      M5.Display.setTextColor(YELLOW);
      M5.Display.println("Weak Signal");
    } else {
      M5.Display.setCursor(5, 50);
      M5.Display.setTextColor(RED);
      M5.Display.println("No Signal");
    }
    
    // ALC状態表示
    M5.Display.setCursor(5, 70);
    M5.Display.setTextColor(CYAN);
    M5.Display.println("ALC: Active");
    
    M5.Display.setTextColor(WHITE);  // 色をリセット
  }
  
  // サンプリング間隔の調整 (約10ms = 100Hz)
  delay(10);
}

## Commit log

2026-01-02 Initial commit: BloodFlowSignal project setup with README and sensor specifications
2026-01-02 Add document on other blood flow measurement methods
2026-01-02 買い物リストを追加
2026-01-03 Add PPG LED ON-OFF frequency implementation guide
2026-01-04 Add Project1_MAX30101: M5AtomS3とMAX30101センサーによる血流計測プロジェクト
2026-01-04 Update: 緑LEDのみ使用に変更、外光ノイズ対策（ALC）を実装
2026-01-04 Add Project2_ICS43434: Blood flow measurement with M5AtomS3 and ICS-43434 microphone
2026-01-04 Add 3D CAD files for ICS-43434 microphone case (STL and STEP formats)
    [microphone_case.step, microphone_case.stl, microphone_lid.step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]
